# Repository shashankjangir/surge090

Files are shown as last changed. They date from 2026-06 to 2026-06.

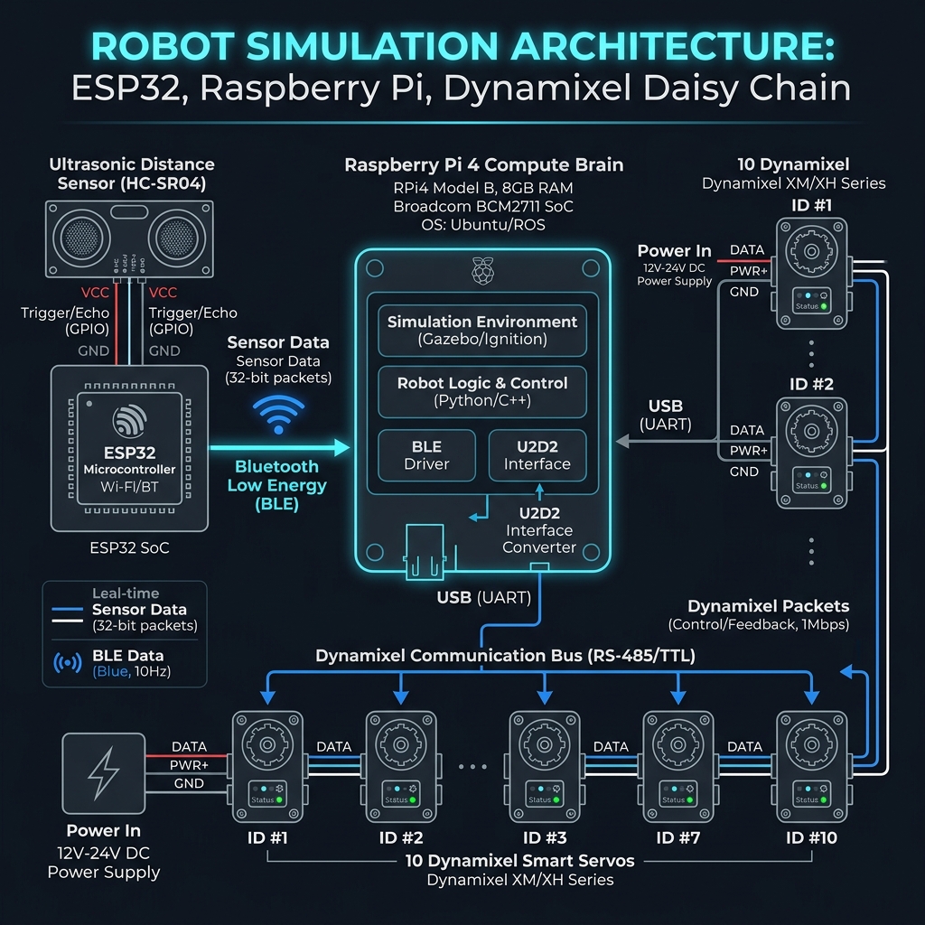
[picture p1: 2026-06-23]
Images/Simulation_Architecture.png

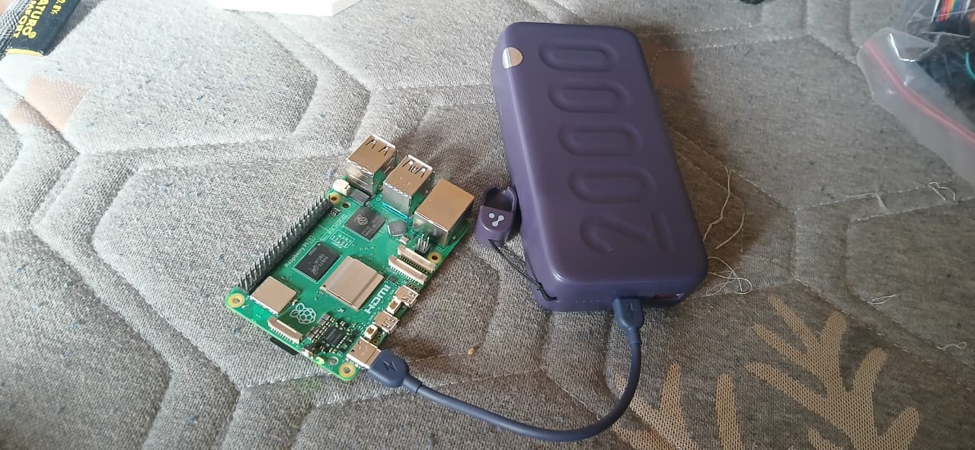
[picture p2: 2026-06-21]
Images/testing/running raspberry pi.jpeg

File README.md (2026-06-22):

        # SURGE-090 · Smart Snake Robot

        **SURGE Summer Research Programme · Indian Institute of Technology Delhi**

        ---

        ## Abstract

        SURGE-090 is a ten-degree-of-freedom, bio-inspired snake robot designed for locomotion in unstructured and confined environments. The platform employs sinusoidal lateral undulation to propel itself forward and uses proprioceptive motor-current sensing as a tactile collision detector — eliminating the need for any external proximity or force sensors. The control architecture is implemented entirely in Python running on a Raspberry Pi, communicating with ROBOTIS Dynamixel XL330 smart servo actuators over a TTL serial daisy chain.

        The project was developed as part of the **SURGE (Summer Undergraduate Research Grant for Excellence)** programme at **IIT Delhi**.

        ---

        ## Table of Contents

        1. [Features](#features)
        2. [System Architecture](#system-architecture)
        3. [Repository Structure](#repository-structure)
        4. [Hardware Requirements](#hardware-requirements)
        5. [Software Setup](#software-setup)
        6. [Running the Robot](#running-the-robot)
        7. [Module Reference](#module-reference)
        8. [CAD Files](#cad-files)
        9. [Documentation](#documentation)
        10. [Team](#team)

        ---

        ## Features

        | Feature | Description |
        |---|---|
        | **10-DOF Serpentine Gait** | Sinusoidal lateral undulation via a travelling sine wave propagated across all joints |
        | **Sensorless Obstacle Detection** | Motor current monitored at 50 Hz; stall current spike (> 350 mA) triggers evasion |
        | **Autonomous Evasion** | State machine: reverse (2.5 s) → side-aware turn (4 s) → resume forward |
        | **Side-Aware Turning** | Sign of the stalling motor's current determines which way the robot evades |
        | **Tethered & Untethered Modes** | Works via USB from a laptop or fully autonomous on on-board Raspberry Pi |
        | **3D-Printed Body** | All structural segments designed in SolidWorks; STEP and STL files provided |

        ---

        ## System Architecture

        ```
        ┌────────────────────────────────────────────┐
        │              Raspberry Pi 5                │
        │                                            │
        │  main.py  ──── Control Loop @ 50 Hz        │
        │     │                                      │
        │     ├──► src/obstacle_avoidance.py         │
        │     │        Current-based state machine   │
        │     │        SLITHER → REV → TURN → ...    │
        │     │                                      │
        │     ├──► src/snake_locomotion.py           │
        │     │        Sinusoidal gait generator     │
        │     │        turn_direction from avoidance │
        │     │                                      │
        │     └──► Dynamixel SDK                     │
        │               write4ByteTxRx (positions)   │
        │               read2ByteTxRx  (current)     │
        └──────────────┬─────────────────────────────┘
                │ USB  ←→  ROBOTIS U2D2
                ┌──────┴──────┐
                │  U2D2 + PHB  │  (power injection at 5V)
                └──────┬───────┘
                │ X3P TTL cables — daisy chain
        ┌───────────▼──────────────────────────────┐
        │  Motor 1 → Motor 2 → … → Motor 10        │
        │       ROBOTIS Dynamixel XL330-M288-T      │
        └───────────────────────────────────────────┘
        ```

        **Obstacle Evasion State Machine**

        ```
        SLITHER ──(|I| > 350 mA)──► SLITHER_REV (2.5 s)
                                        │
                                (timer expires)
                                        ▼
                                SLITHER_TURN (4.0 s)
                                        │
                                (timer expires)
                                        ▼
                                SLITHER
        ```

        ---

        ## Repository Structure

        ```
        surge090/
        ├── main.py                          # Entry point — 50 Hz control loop
        ├── servo_test.py                    # ⚠ DEPRECATED — SG90 GPIO prototype only
        ├── requirements.txt                 # Python dependencies
        ├── install_requirements.cmd         # Windows one-click installer
        ├── reorganise.ps1                   # Repo restructuring utility (run once)
        │
        ├── src/                             # Core robot software
        │   ├── __init__.py
        │   ├── robot_config.py              # All hardware constants & tuning parameters
        │   ├── utils.py                     # Shared utilities (current sign conversion)
        │   ├── snake_locomotion.py          # Sinusoidal gait engine
        │   ├── obstacle_avoidance.py        # Collision state machine
        │   ├── kinematics.py                # Bellows-model joint angle calculator
        │   ├── servo_driver.py              # HAL — mock + Dynamixel SDK interface
        │   └── torque_controller.py         # PD torque controller with compliance
        │
        ├── tests/                           # Hardware validation scripts
        │   ├── test_dynamixel_ping.py       # Ping all motors; report missing IDs
        │   └── test_motor_feedback.py       # Live position / velocity / current readout
        │
        ├── docs/                            # All project documentation
        │   ├── reports/
        │   │   ├── hardware_bom.md          # Bill of Materials (budget: ₹1,00,000)
        │   │   ├── starter_kit_manual.md    # First-time single-motor setup guide
        │   │   └── README_v1.md             # Archived v1 README
        │   ├── datasheets/
        │   │   ├── XL,XC-330.pdf            # ROBOTIS XL330 / XC330 datasheet
        │   │   ├── DYNAMIXEL_XL330_1__52682.png
        │   │   └── Raspberry-Pi-5-Pinout-.jpg
        │   ├── presentations/
        │   │   └── Smart_Snake_Robot_SURGE090_Progress_Review - Repaired.pptx
        │   ├── Component_flow.png           # System component flow diagram
        │   ├── SSH_LOGIN_INSTRUCTIONS.md
        │   ├── wiring_diagram.md
        │   ├── raspberry_pi_setup_guide.md
        │   ├── parts_and_safety.md
        │   └── additional_parts_spreadsheet.md
        │
        ├── cad/                             # SolidWorks / STEP / STL design files
        │   ├── segments/
        │   │   ├── segment1.SLDPRT / .STEP / _v1.STL
        │   │   └── segement2.SLDPRT / .STEP / _v1.STL
        │   ├── assembly/
        │   │   └── assembly.SLDASM
        │   └── motor_models/
        │       ├── XL,XC-330.stp           # Dynamixel motor reference model
        │       └── XL,XC-330.SLDASM
        │
        └── images/
        ├── hardware/                    # Motor & electronics product photos
        ├── cad/                         # CAD render screenshots
        └── testing/                     # Hardware test photos & demo video
        ```

        ---

        ## Hardware Requirements

        | Component | Qty | Approx. Cost (INR) | Notes |
        |---|:---:|---:|---|
        | Dynamixel XL330-M288-T | 10 + 2 spares | ₹36,000 | Core joints; 0.52 Nm @ 5V |
        | ROBOTIS U2D2 (USB-TTL) | 1 | ₹4,500 | Serial bridge to motors |
        | U2D2 Power Hub Board (PHB) | 1 | ₹1,500 | 5V power injection into bus |
        | Raspberry Pi 4 / 5 (4 GB) | 1 | ₹5,500 | On-board compute (optional for tethered) |
        | 5V / 10–20A SMPS *(tethered)* | 1 | ₹2,000 | Mean Well LRS-100-5 recommended |
        | *or* 2S LiPo + 5V UBEC *(untethered)* | 1 | ₹3,500 | Portable power option |
        | Dynamixel X3P Cables (×10) | 1 pack | ₹1,500 | Daisy-chain data + power |
        | F623ZZ Flange Bearings | 10 | ₹1,000 | Load relief for servo horns |
        | Braided Expandable Sleeving | 1 m | ₹2,000 | Robot "skin" — provides traction |
        | M2 / M2.5 Machine Screws | 1 kit | ₹500 | Mount 3D-printed brackets to motors |
        | **Total** | | **≈ ₹52,500** | Out of ₹1,00,000 budget |

        > Full specifications: [`docs/reports/hardware_bom.md`](docs/reports/hardware_bom.md)

        ---

        ## Software Setup

        ### Prerequisites

        - Python 3.8+
        - ROBOTIS U2D2 connected via USB

        ### 1. Clone

        ```bash
        git clone https://github.com/<org>/surge090.git
        cd surge090
        ```

        ### 2. Install Dependencies

        **Windows (one-click):**
        ```cmd
        install_requirements.cmd
        ```

        **Any platform:**
        ```bash
        pip install -r requirements.txt
        ```

        > Dependencies: `dynamixel-sdk >= 4.0.5`, `pyserial >= 3.5`

        ### 3. Set COM Port

        Open [`main.py`](main.py) and confirm the serial port for your system:

        ```python
        # Windows
        DEVICENAME = 'COM3'

        # Linux / Raspberry Pi
        DEVICENAME = '/dev/ttyUSB0'
        ```

        Find the correct port in **Device Manager** (Windows) or `ls /dev/ttyUSB*` (Linux).

        ### 4. Assign Motor IDs

        All motors ship with ID `1`. Assign unique IDs 1–10 one motor at a time:

        1. Plug in **one motor** to the U2D2 PHB.
        2. Open **Dynamixel Wizard 2.0** → Scan → change ID (1 through 10).
        3. Unplug; repeat for next motor.

        > Only after all 10 motors have unique IDs should you daisy-chain them together.

        ### 5. SSH to Raspberry Pi (if running untethered)

        ```powershell
        ssh smartsnake@snakerobo.local
        ```

        Full guide: [`docs/SSH_LOGIN_INSTRUCTIONS.md`](docs/SSH_LOGIN_INSTRUCTIONS.md)

        ---

        ## Running the Robot

        ### Verify All Motors

        ```bash
        python tests/test_dynamixel_ping.py
        ```

        Reports each motor ID found on the bus and explicitly lists any that are missing.

        ### Calibrate Obstacle Threshold

        ```bash
        python tests/test_motor_feedback.py
        ```

        Streams live Position / Velocity / Current (mA). Gently resist the horn to see the current spike that triggers obstacle detection.

        ### Start the Snake

        ```bash
        python main.py
        ```

        The snake initialises all motors, then begins the sinusoidal slither gait. Press **Ctrl + C** to halt — all motor torques are disabled cleanly in the `finally` block.

        ---

        ## Module Reference

        | Module | Class | Description |
        |---|---|---|
        | [`src/robot_config.py`](src/robot_config.py) | `Config`, `DynamixelAddr` | All hardware constants, tuning parameters, control table addresses |
        | [`src/utils.py`](src/utils.py) | — | `to_signed_current()` — XL330 two's complement current conversion |
        | [`src/snake_locomotion.py`](src/snake_locomotion.py) | `SnakeKinematics` | Sinusoidal gait: computes goal encoder positions for all joints |
        | [`src/obstacle_avoidance.py`](src/obstacle_avoidance.py) | `ObstacleAvoidance` | Current-based state machine; side-aware evasion turn direction |
        | [`src/kinematics.py`](src/kinematics.py) | `Kinematics` | Bellows-model curvature wave → joint angles (radians) |
        | [`src/servo_driver.py`](src/servo_driver.py) | `ServoDriver` | Hardware abstraction layer; mock simulation backend |
        | [`src/torque_controller.py`](src/torque_controller.py) | `TorqueController` | PD torque control with shape & radius modification modules |

        ### Gait Parameters (`src/robot_config.py`)

        | Parameter | Value | Description |
        |---|---|---|
        | `NUM_JOINTS` | 10 | Number of motors in daisy chain |
        | `ENCODER_CENTER` | 2048 | Neutral position (0° for XL330, range 0–4095) |
        | `OBSTACLE_CURRENT_THRESHOLD_MA` | 350 mA | Stall detection threshold |
        | `EVASION_REVERSE_DURATION_S` | 2.5 s | Time to reverse before turning |
        | `EVASION_TURN_DURATION_S` | 4.0 s | Time in turning gait before resuming |
        | `MAX_TORQUE_NM` | 0.52 Nm | XL330 stall torque (per ROBOTIS datasheet @ 5V) |

        ---

        ## CAD Files

        Designed in **SolidWorks**; exported to STEP and STL for cross-platform use.

        | File | Location | Description |
        |---|---|---|
        | `segment1.SLDPRT / .STEP / _v1.STL` | `cad/segments/` | Primary body segment |
        | `segement2.SLDPRT / .STEP / _v1.STL` | `cad/segments/` | Secondary body segment |
        | `assembly.SLDASM` | `cad/assembly/` | Full 10-motor robot assembly |
        | `XL,XC-330.stp` | `cad/motor_models/` | Dynamixel motor reference model |

        > Print settings: PLA or PETG recommended; 20% infill; 0.2 mm layer height.

        ---

        ## Documentation

        | Document | Path | Description |
        |---|---|---|
        | Hardware BOM | [`docs/reports/hardware_bom.md`](docs/reports/hardware_bom.md) | Full parts list with pricing |
        | Starter Kit Manual | [`docs/reports/starter_kit_manual.md`](docs/reports/starter_kit_manual.md) | Single-motor first-time setup |
        | Wiring Diagram | [`docs/wiring_diagram.md`](docs/wiring_diagram.md) | Power + data flow (Mermaid + text) |
        | Raspberry Pi Setup | [`docs/raspberry_pi_setup_guide.md`](docs/raspberry_pi_setup_guide.md) | OS configuration guide |
        | SSH Login | [`docs/SSH_LOGIN_INSTRUCTIONS.md`](docs/SSH_LOGIN_INSTRUCTIONS.md) | Connecting to the Pi from Windows |
        | Parts & Safety | [`docs/parts_and_safety.md`](docs/parts_and_safety.md) | Handling & safety guidelines |
        | Additional Parts | [`docs/additional_parts_spreadsheet.md`](docs/additional_parts_spreadsheet.md) | Supplementary components |
        | Progress Presentation | [`docs/presentations/`](docs/presentations/) | SURGE review slides |
        | Datasheets | [`docs/datasheets/`](docs/datasheets/) | XL330 datasheet, Pi pinout |

        ---

        ## Team

        **SURGE-090 — Smart Snake Robot**
        Indian Institute of Technology Delhi — Summer 2026

        | Member | Role |
        |---|---|
        | Shashank Jangir | Project Lead / Software |
        | Bhavesh | Hardware & Mechanical |
        | Mahima | Electronics & Wiring |

        ---

        ## Acknowledgements

        This project was carried out under the **SURGE (Summer Undergraduate Research Grant for Excellence)** programme at **IIT Delhi**. We thank our project supervisor and the Department of Mechanical Engineering for their guidance and laboratory resources.

        ---

        ## License

        © 2026 SURGE-090 Team, IIT Delhi. All rights reserved.
        This repository is shared for academic and research purposes only.

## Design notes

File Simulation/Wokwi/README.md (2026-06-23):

# SURGE-SNAKE ESP32 Sensor Node Wokwi Simulation

This directory contains the Wokwi simulation configuration and source code for the head-mounted distance sensor node.

## Hardware Configuration (`diagram.json`)

The simulation runs on an **ESP32 DevKit v4** connected to a **HC-SR04 Ultrasonic Distance Sensor**:
*   **VCC** -> ESP32 5V
*   **GND** -> ESP32 GND
*   **TRIG** -> ESP32 GPIO 5 (Output)
*   **ECHO** -> ESP32 GPIO 18 (Input)

## Firmware (`sketch.ino`)

The firmware:
1.  Triggers the HC-SR04 sensor at **10 Hz**.
2.  Reads the pulse-width echo response.
3.  Calculates the distance to any head-on obstacles in centimeters.
4.  Initializes the ESP32's Bluetooth stack and broadcasts as a Classic Bluetooth Serial device named `SURGE-SNAKE-ESP32`.
5.  Continuously transmits the data packet format `"DIST:<distance_cm>\r\n"` over Bluetooth Serial.

## How to Run the Wokwi Simulation

1.  Open [Wokwi.com](https://wokwi.com).
2.  Start a new ESP32 project.
3.  Replace the default `diagram.json`, `sketch.ino`, and `libraries.txt` with the files in this directory.
4.  Click the **Start Simulation** button in Wokwi.
5.  Observe the distance output printed in the virtual Serial Terminal. Drag the slider on the simulated HC-SR04 component to change the distance and see the outputs update dynamically.

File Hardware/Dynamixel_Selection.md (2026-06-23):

# SURGE-SNAKE Actuator Selection: ROBOTIS Dynamixel XL330

This document outlines the engineering rationale behind standardizing on the **ROBOTIS Dynamixel XL330-M288-T** smart servo motors for the SURGE-090 snake robot project.

---

## 1. Actuator Comparison

A comparison of candidate actuators was conducted to assess suitability for a 10-degree-of-freedom (10-DOF) bio-inspired snake robot:

| Parameter | TowerPro SG90 (Micro Servo) | Dynamixel AX-12A (Classic) | Dynamixel XL330-M288-T (Selected) |
| :--- | :--- | :--- | :--- |
| **Control Interface** | PWM (Open loop) | TTL Half-Duplex (1 Mbps) | **TTL Half-Duplex (115200 bps - 1 Mbps)** |
| **Feedback Sensors** | None | Position, Temperature, Load | **Contactless Absolute Encoder, Temp, Load, Current** |
| **Operating Voltage**| 4.8V - 6.0V | 9.0V - 12.0V | **3.7V - 6.0V (Standard 5.0V)** |
| **Stall Torque** | 0.18 Nm @ 5V | 1.50 Nm @ 12V | **0.52 Nm @ 5V** |
| **Weight** | 9 grams | 54 grams | **18 grams** |
| **Resolution** | N/A | 0.29° (10-bit potentiometer) | **0.088° (12-bit magnetic absolute encoder)** |
| **Daisy Chainable** | No (requires individual PWM lines) | Yes | **Yes** |

---

## 2. Selection Rationale

### A. Real-Time Proprioceptive Current Feedback (Critical)
The defining feature of the SURGE-090 control system is **sensorless tactile collision detection**. Traditional micro servos (like SG90) do not report operational current or load. The Dynamixel XL330 features an internal current sensor that is readable over the register map (`Present_Current` address `126`). 
By monitoring the motor current at 50 Hz, we can detect torque spikes (> 350 mA) corresponding to external obstacle resistance. This allows the robot to sense collisions across any part of its body without a single external tactile or force sensor.

### B. Weight and Scale Optimization
For snake robots, torque-to-weight ratio is crucial. 
*   **AX-12A** motors are too heavy (54g each, totaling 540g for 10 joints). This would require significantly larger structural linkages and higher torques just to lift the snake's own body.
*   **XL330** weighs only 18g (180g total for 10 joints), keeping the mechanical structure incredibly light and highly agile.

### C. Standard 5.0V Voltage Rail
Unlike the larger AX-12A or XM430 motors which require 12.0V, the XL330 is optimized for **5.0V operation**. 
*   Allows the use of a simple 5V SMPS or a standard 2S LiPo battery with a buck converter.
*   Significantly lowers the voltage hazards and weight of the battery pack.

### D. Single-Bus Daisy Chaining
Instead of running 10 separate PWM wires down the length of the snake (which would result in cable tangling, high friction, and restricted bending), the TTL bus allows a single 3-pin cable (X3P) to daisy-chain all 10 joints sequentially. The entire robot interfaces with the host computer (Raspberry Pi 4) via a single USB-to-TTL bridge (Robotis U2D2).

---

## 3. XL330-M288-T Technical Details

*   **Gear Ratio:** 288.4 : 1
*   **No-load Speed:** 39 rpm (at 5.0V)
*   **Stall Current:** 1.5 A
*   **Control Modes:** Current Control, Velocity Control, Position Control (0° - 360°), Extended Position Control (Multi-turn), Current-based Position Control, PWM Control.
*   **Communication Protocol:** Dynamixel Packet 2.0

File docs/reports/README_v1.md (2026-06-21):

# 🐍 SURGE-090: Self-Adaptive Smart Snake Robot

A bio-inspired, autonomous snake robot built on **Raspberry Pi** and **ROBOTIS Dynamixel XL330** servo motors. SURGE-090 uses a sinusoidal lateral undulation gait to slither forward and detects obstacles using only motor current feedback — no external sensors required.

---

## 📽️ Demo

> Hardware test footage is available in the project working folder.

---

## ✨ Key Features

- **10-DOF Serpentine Locomotion** — Sinusoidal lateral undulation gait implemented in pure Python
- **Sensorless Obstacle Detection** — Monitors motor current draw; a current spike (> 350 mA) signals a collision
- **Autonomous Evasion State Machine** — Automatically reverses for 2.5 s → turns for 4 s → resumes forward slither
- **Dual Operation Modes** — Tethered (via laptop USB) or fully untethered (on-board Raspberry Pi)
- **3D-Printed Body Segments** — SolidWorks + STEP + STL files included for all structural parts

---

## 🏗️ System Architecture

```
┌───────────────────────────────────────┐
│           Raspberry Pi 5              │
│                                       │
│  main.py  (Control Loop @ 50 Hz)      │
│    │                                  │
│    ├─► obstacle_avoidance.py          │
│    │     State Machine:               │
│    │     SLITHER → SLITHER_REV        │
│    │              → SLITHER_TURN      │
│    │              → SLITHER           │
│    │                                  │
│    ├─► snake_locomotion.py            │
│    │     Sinusoidal gait generation   │
│    │                                  │
│    └─► servo_driver.py               │
│          Dynamixel SDK calls          │
└──────────────┬────────────────────────┘
               │ USB (Micro-USB)
        ┌──────▼──────┐
        │  ROBOTIS U2D2│ ← USB-to-TTL adapter
        │  + PHB Board │ ← 5V power injection
        └──────┬───────┘
               │ X3P TTL cables (daisy chain)
    ┌──────────▼──────────────────────────┐
    │  Motor 1 ─── Motor 2 ─── ... ─── Motor 10  │
    │     Dynamixel XL330-M288-T          │
    └─────────────────────────────────────┘
```

---

## 📁 Repository Structure

```
git/
├── main.py                     # Entry point: control loop
├── servo_test.py               # Standalone servo testing script
├── requirements.txt            # Python dependencies
├── install_requirements.cmd    # Windows one-click dependency installer
├── hardware_bom.md             # Bill of Materials with costs (budget: ₹1,00,000)
├── starter_kit_manual.md       # Getting started with a single motor
├── SSH_LOGIN_INSTRUCTIONS.md   # How to SSH into the Raspberry Pi
├── Component_flow.png          # System architecture diagram
│
├── src/                        # Core robot logic (Python modules)
│   ├── snake_locomotion.py     # Sinusoidal gait & position calculator
│   ├── kinematics.py           # Joint angle kinematics
│   ├── servo_driver.py         # Low-level Dynamixel SDK wrapper
│   ├── obstacle_avoidance.py   # Current-based collision state machine
│   ├── torque_controller.py    # Torque limits & safety management
│   └── robot_config.py         # Centralized hardware constants
│
├── tests/                      # Hardware validation scripts
│   ├── test_dynamixel_ping.py  # Ping all motors to verify connectivity
│   └── test_motor_feedback.py  # Live motor position, velocity & current readout
│
├── 3d_parts/                   # CAD files for 3D-printed body
│   ├── segment1.SLDPRT / .STEP / .STL
│   ├── segement2.SLDPRT / .STEP / .STL
│   ├── XL,XC-330.stp           # Dynamixel motor reference model
│   └── assembly.SLDASM         # Full robot assembly
│
└── instruction/                # Setup & reference documentation
    ├── raspberry_pi_setup_guide.md
    ├── wiring_diagram.md
    ├── parts_and_safety.md
    └── additional_parts_spreadsheet.md
```

---

## 🛒 Hardware Requirements

| Component | Qty | Approx. Cost |
|---|:---:|---|
| Dynamixel XL330-M288-T (+ 2 spares) | 12 | ₹36,000 |
| ROBOTIS U2D2 (USB-to-TTL adapter) | 1 | ₹4,500 |
| U2D2 Power Hub Board (PHB) | 1 | ₹1,500 |
| Raspberry Pi 4/5 (4 GB) | 1 | ₹5,500 |
| 5V / 10–20A Power Supply *(tethered)* | 1 | ₹2,000 |
| *or* 2S LiPo + 5V UBEC *(untethered)* | 1 | ₹3,500 |
| Dynamixel X3P Cables (pack of 10) | 1 | ₹1,500 |
| F623ZZ Flange Bearings | 10 | ₹1,000 |
| Braided Expandable Sleeving ("skin") | 1 m | ₹2,000 |
| M2 / M2.5 Machine Screw Assortment | 1 | ₹500 |
| **Total** | | **~₹52,500 / ₹1,00,000** |

> See [`hardware_bom.md`](hardware_bom.md) for full specifications and sourcing notes.

---

## ⚙️ Software Setup

### Prerequisites

- Python 3.8+
- A Dynamixel-compatible serial port (USB via U2D2)

### 1. Clone the Repository

```bash
git clone <repo-url>
cd surge090
```

### 2. Install Dependencies

**Windows (one-click):**
```cmd
install_requirements.cmd
```

**Any platform:**
```bash
pip install -r requirements.txt
```

Dependencies: `dynamixel-sdk >= 4.0.5`, `pyserial >= 3.5`

### 3. Set Your COM Port

Open [`main.py`](main.py) and verify the serial port matches your system:

```python
# Windows
DEVICENAME = 'COM3'

# Linux / Raspberry Pi
DEVICENAME = '/dev/ttyUSB0'
```

Check the correct port in **Device Manager** (Windows) or with `ls /dev/ttyUSB*` (Linux).

### 4. Assign Motor IDs

All factory Dynamixel motors ship with ID `1`. You must assign unique IDs 1–10 **one at a time** before daisy-chaining:

1. Plug in **one motor** at a time to the U2D2 PHB.
2. Open **Dynamixel Wizard 2.0** on your PC.
3. Scan and change the motor's ID (1 through 10).
4. Unplug, plug in the next motor, repeat.

---

## 🚀 Running the Robot

### Quick Hardware Test (single motor)

```bash
python tests/test_motor_feedback.py
```

This enables torque, holds center position, and streams live **Position / Velocity / Current (mA)** to the terminal. Try forcing the horn with your fingers to see the current spike that drives obstacle detection.

### Ping All Motors

```bash
python tests/test_dynamixel_ping.py
```

Verifies that all 10 motors respond on the TTL bus.

### Single Servo Test

```bash
python servo_test.py
```

### Full Robot — Main Control Loop

```bash
python main.py
```

The snake will initialize all motors, then begin the sinusoidal slither gait. Press **Ctrl + C** to halt and safely disable all motor torques.

---

## 🧠 How It Works

### Locomotion — Lateral Undulation

Each odd-numbered motor is a **yaw** joint (lateral bending); each even-numbered motor is a **pitch** joint (held flat). The gait is produced by a travelling sine wave propagated along the motor chain:

```
position[i] = center + A · sin(ω·t − i·φ)
```

| Parameter | Value | Description |
|---|---|---|
| `amplitude` | 400 ticks | Peak deflection from centre |
| `frequency` | 3.0 | Wave propagation speed |
| `phase_shift` | 1.2 rad | Phase offset between adjacent segments |
| `center_pos` | 2048 | Neutral encoder count (0° for XL330) |

### Obstacle Avoidance — State Machine

The robot uses **motor current as a tactile sensor**. No external hardware is needed.

```
SLITHER ──(current > 350 mA)──► SLITHER_REV (2.5 s)
                                      │
                              (timer expires)
                                      ▼
                              SLITHER_TURN (4.0 s)
                                      │
                              (timer expires)
                                      ▼
                                  SLITHER
```

---

## 🖥️ Connecting to the Raspberry Pi (SSH)

```powershell
ssh smartsnake@snakerobo.local
```

Password: `xyz@1234`

> Ensure the Pi and your PC are on the same network (Wi-Fi or Ethernet). See [`SSH_LOGIN_INSTRUCTIONS.md`](SSH_LOGIN_INSTRUCTIONS.md) for full details.

---

## 🔌 Wiring Overview

```
Wall Outlet
  └─► 5V/10A Power Supply
        └─► U2D2 PHB (+ and - terminals)
              │
              ├─► U2D2 USB Interface ◄─► Raspberry Pi (USB-A)
              │
              └─► Motor 1 ◄─X3P─► Motor 2 ◄─X3P─► ... ◄─X3P─► Motor 10
```

For the full Mermaid flowchart and step-by-step wiring instructions, see [`instruction/wiring_diagram.md`](instruction/wiring_diagram.md).

---

## 📚 Documentation Index

| Document | Description |
|---|---|
| [`hardware_bom.md`](hardware_bom.md) | Full Bill of Materials with pricing |
| [`starter_kit_manual.md`](starter_kit_manual.md) | First-time setup guide (single motor) |
| [`SSH_LOGIN_INSTRUCTIONS.md`](SSH_LOGIN_INSTRUCTIONS.md) | SSH into the Raspberry Pi |
| [`instruction/raspberry_pi_setup_guide.md`](instruction/raspberry_pi_setup_guide.md) | Configure the Raspberry Pi OS |
| [`instruction/wiring_diagram.md`](instruction/wiring_diagram.md) | Full wiring flowchart & instructions |
| [`instruction/parts_and_safety.md`](instruction/parts_and_safety.md) | Safety guidelines |
| [`instruction/additional_parts_spreadsheet.md`](instruction/additional_parts_spreadsheet.md) | Supplementary parts list |

---

## 🔮 Future Roadmap

- [ ] Head-mounted distance sensor (HC-SR04 / VL53L0X) via ESP32 over Bluetooth
- [ ] 3D terrain navigation (pitch joint activation for vertical obstacles)
- [ ] ROS 2 integration for telemetry and remote control
- [ ] Wireless live dashboard (motor states, current draw, gait mode)

---

## 📄 License

This project is developed as part of the **SURGE-090** research initiative. All rights reserved by the project team.

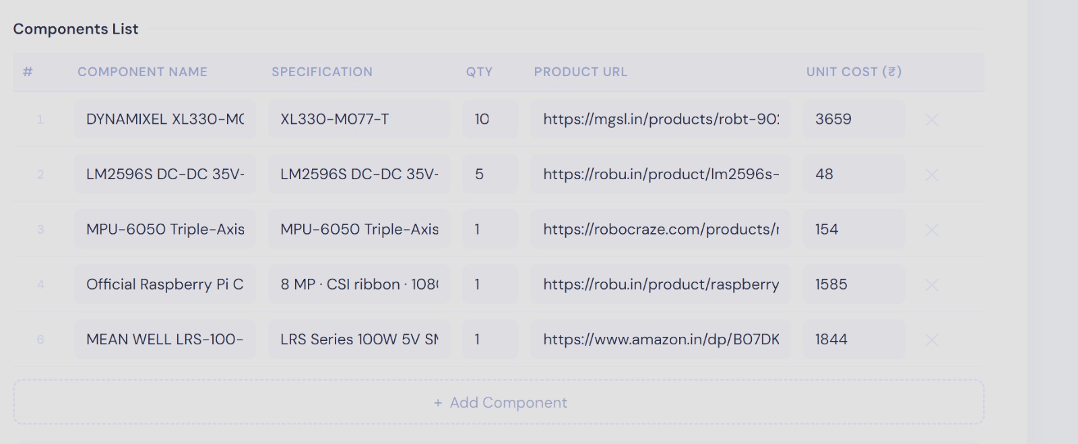
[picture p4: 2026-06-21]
Images/hardware/list 2.jpeg

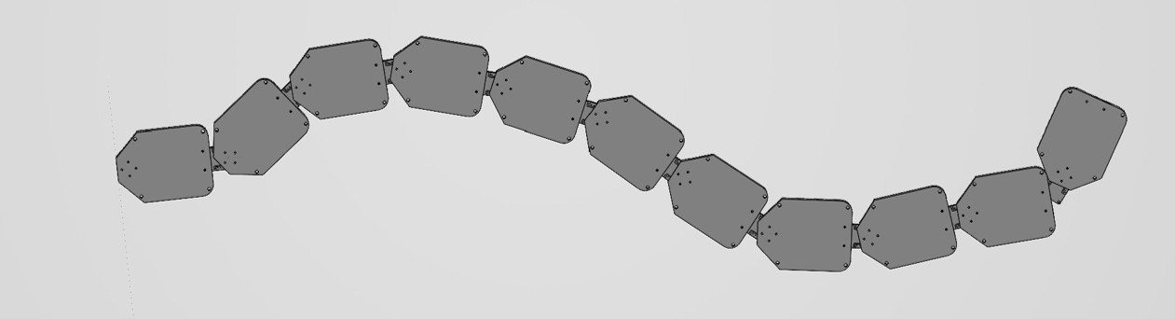
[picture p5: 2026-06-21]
Images/hardware/Picture1.jpg

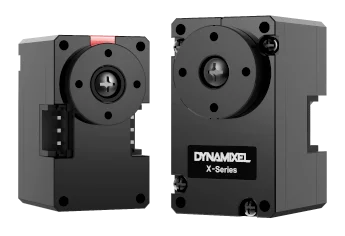
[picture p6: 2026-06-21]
Images/hardware/dynamixel.webp

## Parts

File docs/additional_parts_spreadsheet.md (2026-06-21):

# SURGE-SNAKE Additional Parts Spreadsheet

This document outlines everything else you need to complete the SURGE-SNAKE robot, explicitly **excluding the motors**. The items are separated into expensive structural/power upgrades and standard electronic components.

## 🔴 Expensive / Major Components
*These components represent the bulk of the remaining non-motor budget, primarily focusing on the mechanical structure and untethering the robot from the wall.*

| Component Name | Detailed Specifications | QTY | Est. Price (₹) | Trusted Product Link |
| :--- | :--- | :---: | :---: | :--- |
| **Robot Cable-X3P 180mm** | 3-pin JST TTL cables for Dynamixel X-Series. (Usually sold in packs of 10). You need these to daisy chain the remaining 8 joints. | 1 Pack | 2,659 | [MG Super Labs](https://www.mgsuperlabs.co.in/estore/Robot-Cable-X3P-180mm-10pcs) |
| **3D Printer Filament (PLA+)** | 1kg Spool, 1.75mm. Required to 3D print the custom U-brackets that connect the motors in the alternating pitch/yaw format. | 1 | 1,400 | [Robocraze (eSUN PLA+)](https://robocraze.com/products/esun-pla-pro-filament) |

---

## 🟢 Standard Components & Sensors
*These are the cheaper, everyday electronic components required for sensing, wiring, and friction.*

| Component Name | Detailed Specifications | QTY | Est. Price (₹) | Trusted Product Link |
| :--- | :--- | :---: | :---: | :--- |
| **High-Discharge 2S LiPo Battery** | 7.4V, ~2200mAh, 30C+ discharge rate. (Only needed if you want the snake to be completely wireless). | 1 | 1,200 | [Robocraze (Orange LiPo)](https://robocraze.com/collections/lipo-battery) |
| **VL53L0X Laser ToF Sensor** | High-precision Time-of-Flight laser ranging sensor for the head of the snake. Better accuracy than Ultrasonic. | 1 | 450 | [Robocraze (VL53L0X)](https://robocraze.com/products/gy-53-vl53l0x-laser-tof-flight-time-range-sensor-module) |
| **HC-SR04 Ultrasonic Sensor** | *Alternative to VL53L0X.* Cheaper, bulkier acoustic distance sensor. | 1 | 85 | [Robocraze (HC-SR04)](https://robocraze.com/products/ultrasonic-sensor-hc-sr04) |
| **5V 10A DC-DC Buck Converter** | Step-down module. **CRITICAL** if you buy the 7.4V LiPo battery. It drops the 7.4V down to the safe 5.0V needed for the XL330 motors. | 1 | 600 | [ElectronicsComp / Robocraze](https://robocraze.com/collections/step-down-buck-converter) |
| **Logic Level Shifter** | 4-channel bi-directional (3.3V to 5V). Protects the ESP32's 3.3V pins if you use a 5V sensor. | 1 | 60 | [Robocraze (Level Shifter)](https://robocraze.com/products/4-channel-iic-i2c-logic-level-converter) |
| **Jumper Wires (M-F & F-F)** | 40-pin ribbon cables (Dupont). Needed to wire the front sensor to the ESP32. | 1 Set | 120 | [Robocraze (Jumper Wires)](https://robocraze.com/products/jumper-wires-male-to-female-40-pcs) |
| **18 AWG Silicone Wire** | 1 Meter Red, 1 Meter Black. Thick wire to connect the 5V 10A Power Supply to the U2D2 PHB Terminal Block safely. | 1 | 150 | [Robocraze (Silicone Wire)](https://robocraze.com) |
| **TPU Filament OR Rubber Pads** | **CRITICAL for Locomotion.** Anti-slip rubber adhesive pads (or 3D printed TPU feet) for the underside of the brackets to provide Friction Anisotropy. | 1 Pack | 200 | [Amazon India (Rubber Pads)](https://www.amazon.in) |

---

### Usage Notes:
1. **Friction Pads:** You can simply buy a sheet of adhesive 3M rubber anti-slip pads from Amazon or a local hardware store and cut them into strips for the belly of the snake. You do not need to 3D print these if you don't have TPU filament.
2. **LiPo Battery:** If you stick to using the tethered 5V 10A power supply you already ordered, you can completely ignore the LiPo Battery and the 5V Buck Converter.
3. **Cables:** Ensure the Dynamixel cables you buy are exactly **X3P** (JST connectors), as older Bioloid AX-12 cables will not fit the XL330.

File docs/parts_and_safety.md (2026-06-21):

# SURGE-SNAKE Parts and Safety Protocol

## Parts Ordered (Existing Inventory)
1. **SD card (32GB A1 class 10)** - For Raspberry Pi OS.
2. **Raspberry Pi 4 Model B (4GB RAM)** - Main compute brain.
3. **Power Adapter (USB-C 5V 3A)** - Dedicated power for the Raspberry Pi.
4. **Raspberry Pi Heat Sink (Double Fans)** - Cooling for Pi.
5. **Dynamixel XL330-M288-T (x2)** - Smart servos for the joints (currently 2 for testing).
6. **U2D2 USB Interface** - Translates USB to TTL half-duplex for the Dynamixels.
7. **U2D2 PHB Power Hub Board** - Distributes power and signals to the daisy-chained Dynamixels.
8. **Robot Cable X3P 180mm** - TTL cables to connect motors.
9. **Power Supply (5V 10A - 50W)** - Power source for the Dynamixel network.
10. **ESP32 (38 pin WiFi + Bluetooth)** - Sensor node/secondary controller.

## Missing Parts (To Be Ordered)
Based on the plan for a 10-motor serpentine robot:

1. **Additional Dynamixel XL330-M288-T (x8):** To complete the 10-motor setup (5 pitch, 5 yaw).
2. **Dynamixel X3P Cables (x8):** Need more cables to daisy-chain the new motors.
3. **Mechanical Brackets / Frame:**
   - 3D Printed custom links OR BIOLOID frame components to mechanically connect the motors in alternating Pitch/Yaw configurations.
4. **Friction Pads (CRITICAL):**
   - TPU feet, rubber pads, or passive wheels (that only roll forward/back) attached to the underside of the snake. *Required for Friction Anisotropy so the snake pushes forward instead of wriggling in place.*
5. **Front Obstacle Sensor:** 
   - 1x **HC-SR04** (Ultrasonic) or **VL53L0X** (Time-of-Flight) module to attach to the ESP32 for head-on obstacle detection.
5. **Miscellaneous Wiring:** 
   - Jumper wires to connect ESP32 and sensors.
   - 18 AWG wires to connect the 5V 10A Power Supply to the U2D2 PHB Terminal block.

---

## ⚡ Safety Protocols & Voltage Limits ⚡

> [!CAUTION]
> **CRITICAL: NEVER exceed 6.0V on the Dynamixel XL330 network!**

### 1. Motor Power Line (5V System)
- **Component Limit:** Dynamixel XL330-M288-T operates safely between **3.7V and 6.0V**.
- **Current Setup:** You are using a 5V 10A power supply. This is **PERFECT** and very safe. The U2D2 PHB simply passes the input voltage directly to the motors.
- **Safety Rule:** Ensure the polarity (+ and -) from the 5V power supply to the U2D2 PHB terminal block is correct. Reversing the polarity will permanently damage the U2D2 PHB and the motors.

### 2. Microcontroller Power Limits
- **Raspberry Pi 4:** Must be powered via its official 5V 3A USB-C adapter. Do not back-power it from the U2D2 PHB. Keep the logic connections (USB from Pi to U2D2) isolated from the motor power supply.
- **ESP32:** Can be powered via USB (5V) or via its VIN/VCC pin (5V). Its GPIO pins are **3.3V logic ONLY**. Do not connect a 5V sensor output directly to an ESP32 GPIO pin without a logic level shifter or a voltage divider.

### 3. Untethered / Battery Operation (Future Upgrade)
If you decide to make the snake wireless, you cannot plug a 2S LiPo battery (7.4V - 8.4V) directly into the U2D2 PHB, as it will fry the 6.0V limit XL330 motors.
- **Required Safety Barrier:** You will need a **5V Buck Converter (Step-Down Module)** rated for at least 10 Amps to sit between the LiPo battery and the U2D2 PHB.

### 4. Overcurrent & Stall Safety
The Python code includes software safety limits to prevent motors from burning out if the snake gets stuck on an obstacle:
- We read the `Present_Current` of each Dynamixel. 
- If the current exceeds a set threshold (e.g., indicating a stall or collision), the robot will automatically halt and execute an avoidance maneuver.

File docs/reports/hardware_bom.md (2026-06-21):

# Hardware Bill of Materials (Budget: ₹1,00,000)

This document contains the finalized hardware required to build the 10-motor **SURGE-SNAKE** using the Dynamixel ecosystem. 

With a budget of **1 Lakh (₹1,00,000)** and standardizing on the **Dynamixel XL330-M288** motors, the project comes in significantly under budget, leaving plenty of room for spares, future sensor upgrades, and high-quality mechanical components.

---

## 1. Core Actuators (Servos) - *Require 10 Units*

| Component | Specs & Torque | Approx. Cost (10 Units) | Role in Robot |
| :--- | :--- | :--- | :--- |
| **Dynamixel XL330-M288-T** | 0.5 Nm, 5V, Contactless Absolute Encoder | ~₹30,000 (₹3k ea) | The core joints of the snake. Provides extremely precise position, velocity, and current (load) feedback crucial for obstacle avoidance. |
| **Spare Motors** | Same as above | ~₹6,000 (2 extra) | Highly recommended to buy 2 spares in case of gear stripping during extreme physical testing. |

---

## 2. Computing Brain & Interface

The Dynamixel motors require a dedicated USB interface to talk to your computer or Raspberry Pi.

| Component | Specs | Approx. Cost | Role in Robot |
| :--- | :--- | :--- | :--- |
| **Robotis U2D2** | USB to TTL Converter | ~₹4,500 | Plugs into your PC/Pi and outputs the 3-pin TTL data signal for the Dynamixel motors. |
| **Robotis U2D2 Power Hub Board (PHB)** | Power Injector | ~₹1,500 | Mounts to the U2D2. Combines the data signal with raw 5V power so the motors don't fry your USB port. |
| **Raspberry Pi 4 (Optional)** | 4GB RAM, Linux OS | ~₹5,500 | If you want the snake untethered from your laptop, the Pi will run the `main.py` Python code onboard. |

---

## 3. Power Supply

The **XL330-M288** motors require **5 Volts** (not 12V!). Powering 10 motors at stall torque requires roughly 10 Amps to 15 Amps of current.

| Component Option | Specs | Approx. Cost | Pros / Cons |
| :--- | :--- | :--- | :--- |
| **Mean Well LRS-100-5 (Tethered)** | 5V, 20A Industrial SMPS | ~₹2,000 | **Pros:** Extremely reliable, clean power for testing on a desk.<br>**Cons:** Keeps the snake tethered to the wall. |
| **2S LiPo Battery + 5V UBEC (Untethered)** | 7.4V LiPo + 10A 5V Step-Down | ~₹3,500 | **Pros:** Makes the snake fully wireless.<br>**Cons:** Requires careful voltage monitoring and a fire-safe charger. |

---

## 4. Wiring & Mechanical Setup

| Component | Specs | Approx. Cost |
| :--- | :--- | :--- |
| **Dynamixel X3P Cables** | 100mm to 150mm lengths (Pack of 10) | ~₹1,500 | Daisy-chains the data and power from one motor to the next. |
| **F623ZZ Flange Bearings** | For opposite side of servo horn | ~₹1,000 | Takes the mechanical load off the servo horn, preventing snapped shafts. |
| **Braided Expandable Sleeving** | Rubberized mesh tube | ~₹2,000 | Acts as the "skin" of the snake. Expands as it bends and provides traction against the floor. |
| **M2 & M2.5 Machine Screws** | Assorted Kit | ~₹500 | For mounting the 3D printed brackets to the Dynamixels. |

---

## Summary Recommendation 

**Total Estimated Cost: ~₹52,500 INR** (out of ₹1,00,000 budget)

Standardizing on the **Dynamixel XL330-M288** is highly efficient. It operates at 5V, saving weight on batteries, and integrates perfectly with the official Robotis `dynamixel_sdk`. The Python code provided in this repository is designed specifically for this exact hardware list.

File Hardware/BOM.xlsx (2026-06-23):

SURGE-SNAKE Hardware Bill of Materials
Total Budget: INR 1,00,000 | Standardized on Dynamixel XL330 Ecosystem
1. Core Actuators (Servos)
Component | Specs & Torque | Qty | Unit Price (INR) | Total Price (INR) | Role in Robot
Dynamixel XL330-M288-T | 0.52 Nm @ 5V, Contactless Absolute Encoder | 10 | ₹3000 | ₹30000 | Core joints of the snake robot. Provides precise position, velocity, and current feedback.
Spare Motors | Same as above | 2 | ₹3000 | ₹6000 | Recommended spares for testing and replacement.
Subtotal
2. Computing Brain & Interface
Component | Specs | Qty | Unit Price (INR) | Total Price (INR) | Role in Robot
Robotis U2D2 | USB to TTL Serial Converter | 1 | ₹4500 | ₹4500 | Plugs into computer/Pi to translate USB to TTL half-duplex signals.
Robotis U2D2 Power Hub Board (PHB) | Power Injector Board | 1 | ₹1500 | ₹1500 | Combines power and TTL signals for daisy-chained motors.
Raspberry Pi 4 | 4GB RAM, Linux OS, USB-C Power | 1 | ₹5500 | ₹5500 | On-board compute brain running python control loop.
Subtotal
3. Power Supply
Component | Specs | Qty | Unit Price (INR) | Total Price (INR) | Pros / Cons
Mean Well LRS-100-5 (Tethered) | 5V, 20A Industrial SMPS | 1 | ₹2000 | ₹2000 | Pros: extremely reliable, clean power for testing. Cons: tethered.
2S LiPo Battery + 5V UBEC (Untethered) | 7.4V LiPo + 10A 5V Step-Down Converter | 1 | ₹3500 | ₹3500 | Pros: makes robot wireless. Cons: requires voltage monitoring.
Subtotal
4. Wiring & Mechanical Setup
Component | Specs | Qty | Unit Price (INR) | Total Price (INR) | Notes
Dynamixel X3P Cables | 100mm to 150mm length (Pack of 10) | 1 | ₹1500 | ₹1500 | Daisy-chains power and data between adjacent joints.
F623ZZ Flange Bearings | Load relief bearings | 10 | ₹100 | ₹1000 | Relieves radial loads off the servo horn, preventing shaft failure.
Braided Expandable Sleeving | Rubberized mesh tube (1 meter) | 1 | ₹2000 | ₹2000 | Acts as the snake skin; provides friction anisotropy and protection.
M2 & M2.5 Machine Screws | Assorted Fastener Kit | 1 | ₹500 | ₹500 | For mounting custom 3D printed brackets to motor frames.
Subtotal
GRAND TOTAL

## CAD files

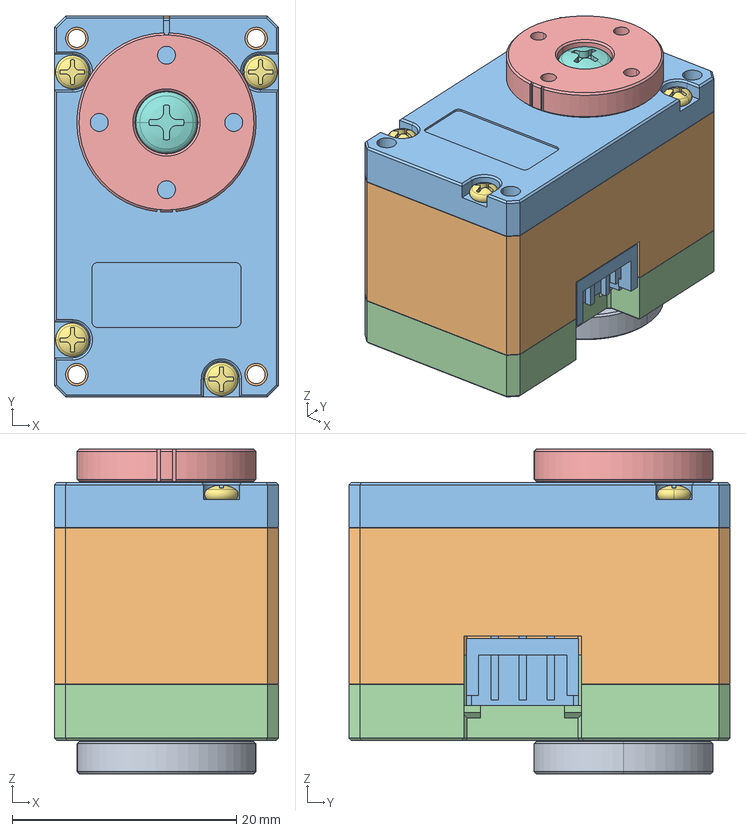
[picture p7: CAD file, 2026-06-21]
CAD/motor_models/XL,XC-330.stp
20.0 x 34.0 x 29.0 mm
DC15_A01_CASE_M_DUMMY
DC15_A01_CASE_F_DUMMY
DC15_A01_CASE_B_DUMMY
DC15_A01_HORN_DUMMY
DC15_A01_LED_CAP2_DUMMY
PHS_1_7X20_5_DC10 x 4
BTS2_M2_6X8 x 2
DC15_A01_HORN_IDLE2_DUMMY
DC15_A01_IDLE_CAP_DUMMY
B3B-EH x 2

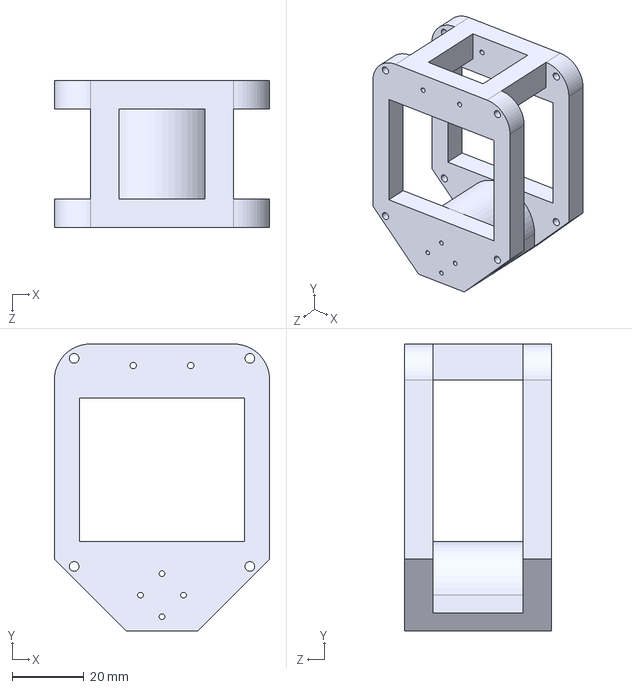
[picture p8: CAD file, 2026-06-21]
CAD/segments/segement2.STEP
60.0 x 80.0 x 41.0 mm

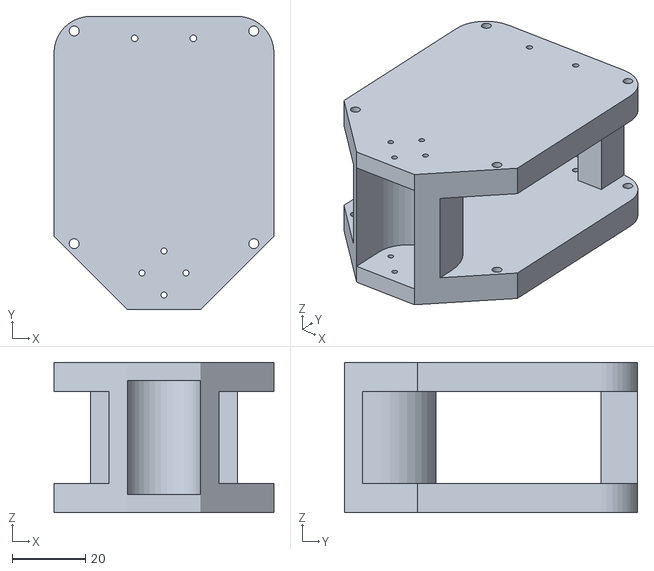
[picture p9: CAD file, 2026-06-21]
CAD/segments/segment1_v1.STL
60.0 x 80.0 x 41.0

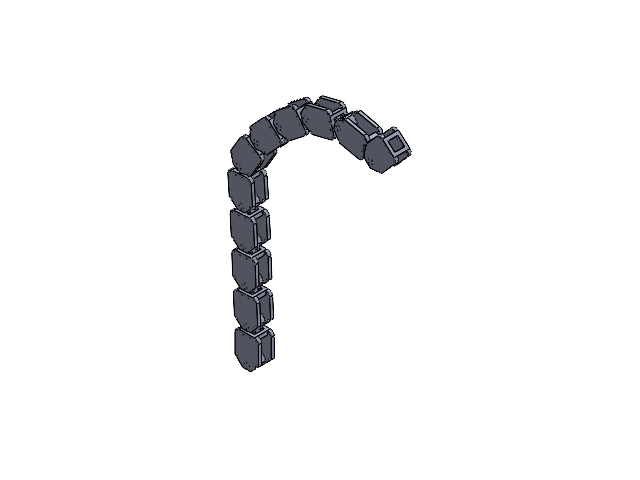
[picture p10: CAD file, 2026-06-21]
CAD/assembly/assembly.SLDASM
segment1 (2) x 11
DC15_A01_CASE_M_DUMMY.stp x 10
DC15_A01_CASE_F_DUMMY.stp x 10
DC15_A01_CASE_B_DUMMY.stp x 10
DC15_A01_HORN_DUMMY.stp x 10
DC15_A01_LED_CAP2_DUMMY.stp x 10
PHS_1_7X20_5_DC10.stp x 40
BTS2_M2_6X8.stp x 20
DC15_A01_HORN_IDLE2_DUMMY.stp x 10
DC15_A01_IDLE_CAP_DUMMY.stp x 10
B3B-EH.stp x 20

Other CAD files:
CAD/segments/segement2_v1.STL
CAD/segments/segment1.STEP
CAD/segments/segment1 (2).SLDPRT
CAD/motor_models/XL,XC-330.SLDASM
CAD/segments/segement2.SLDPRT
CAD/segments/segment1.SLDPRT

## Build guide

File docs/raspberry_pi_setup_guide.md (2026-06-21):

# SURGE-SNAKE: Raspberry Pi Setup & Execution Guide

This guide will walk you through flashing the OS, deploying this code to your Raspberry Pi, and running the physical robot.

## Phase 1: Burning the Raspberry Pi OS
Since the Pi will sit inside the snake, it will run "headless" (without a monitor).

1. **Download Raspberry Pi Imager:** Install it on your Windows PC from the official Raspberry Pi website.
2. **Insert SD Card:** Plug the 32GB SD card into your PC.
3. **Configure Imager:**
   - **Device:** Select `Raspberry Pi 4`.
   - **OS:** Choose `Raspberry Pi OS (64-bit)` (Lite is fine if you don't need a desktop UI, otherwise choose Full).
   - **Storage:** Select your 32GB SD Card.
4. **OS Customization (Crucial for Headless Setup):**
   - Click the gear icon (or "Edit Settings") before writing.
   - Check **Set hostname** (e.g., `surgesnake.local`).
   - Check **Enable SSH** (Use password authentication).
   - Set **Username and Password** (e.g., user: `pi`, pass: `password`).
   - Check **Configure wireless LAN** and enter your home Wi-Fi SSID and Password.
5. **Write:** Click "Write" to burn the OS.

---

## Phase 2: Hardware Wiring & Booting
1. Insert the flashed SD card into the Raspberry Pi.
2. Plug the USB-C 5V 3A adapter into the Pi to boot it up.
3. Plug the **U2D2 Interface** into one of the Pi's USB ports.
4. Connect the **5V 10A Power Supply** to the **U2D2 PHB Power Board** (Double check positive/negative polarity!).
5. Daisy-chain your 2 Dynamixel motors to the U2D2 PHB.

---

## Phase 3: Accessing the Pi and Installing Dependencies
Wait about 2 minutes for the Pi to boot and connect to your Wi-Fi.

1. Open PowerShell on your Windows PC and SSH into the Pi:
   ```bash
   ssh pi@surgesnake.local
   ```
   *(Accept the fingerprint prompt and enter your password).*
2. Once inside the Pi, update the system and install the required Python libraries:
   ```bash
   sudo apt update
   sudo apt upgrade -y
   sudo apt install python3-pip
   pip install dynamixel-sdk pyserial
   ```
3. Add your user to the `dialout` group so Python can access the USB port without root permissions:
   ```bash
   sudo usermod -aG dialout pi
   ```
   *You must log out and log back in (or reboot the Pi) for this to take effect.*

---

## Phase 4: Copying the Code (Windows to Pi)
You have this `SURGE-SNAKE` folder on your Windows Desktop. We need to send it to the Pi.

### Method A: Using SCP (Command Line)
Open a **new** PowerShell window on your Windows PC (not the SSH session) and run:
```bash
scp -r "C:\Users\bansi\OneDrive\Desktop\SURGE-SNAKE" pi@surgesnake.local:/home/pi/
```
This will copy the entire folder over the network.

### Method B: Using WinSCP (GUI)
1. Download and install [WinSCP](https://winscp.net/).
2. Connect to `surgesnake.local` using your Pi's username and password.
3. Drag and drop the `SURGE-SNAKE` folder from your desktop into the `/home/pi/` directory.

> **Note on USB Ports:** 
> I have already updated the Python scripts to automatically detect that they are running on a Raspberry Pi (Linux) and they will look for the U2D2 at `/dev/ttyUSB0` instead of `COM3`. You do not need to manually change the code!

---

## Phase 5: Testing & Running
SSH back into your Pi (`ssh pi@surgesnake.local`) and navigate to the folder:
```bash
cd SURGE-SNAKE
```

**1. Ping the Motors:**
```bash
python3 tests/test_dynamixel_ping.py
```
*You should see output confirming communication with Motor 1 and Motor 2.*

**2. Test Obstacle Load Detection:**
```bash
python3 tests/test_motor_feedback.py
```
*Squeeze the motor lightly while it spins; watch the current/mA reading spike.*

**3. Run the Main Snake Loop:**
```bash
python3 main.py
```
*The motors will begin executing the rolling helix wave. If you grab one, it will trigger the reverse-and-turn evasion sequence!*

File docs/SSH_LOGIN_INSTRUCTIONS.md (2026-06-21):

# Raspberry Pi SSH Login Instructions

These are the step-by-step instructions to log into the Raspberry Pi from your Windows computer.

## Prerequisites
- Ensure your Raspberry Pi is powered on.
- Ensure your Raspberry Pi is on the same network as your PC. This means EITHER:
  - You have an **Ethernet cable** directly connecting the Pi to your PC.
  - OR, both devices are connected to the same **Wi-Fi network / hotspot**.

## Login Steps

**Step 1: Open PowerShell**
1. Press the **Windows Key** on your keyboard.
2. Type `PowerShell` and press **Enter**.

**Step 2: Enter the SSH Command**
In the PowerShell window, type the following command and press **Enter**:
```powershell
ssh smartsnake@snakerobo.local
```

**Step 3: Security Prompt (First Time Only)**
If you see a message asking: `Are you sure you want to continue connecting (yes/no/[fingerprint])?`
Type `yes` and press **Enter**.

**Step 4: Enter Password**
When prompted for the password, type:
```text
xyz@1234
```
*Note: The password will **not** appear on the screen as you type it. This is a normal security feature. Just type the characters and press **Enter**.*

## Success!
Once you see the prompt change to `smartsnake@snakerobo:~ $`, you are successfully logged into the Raspberry Pi and can start running commands.

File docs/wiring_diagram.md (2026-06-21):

# SURGE-SNAKE Wiring & Circuit Diagram

This document contains the exact wiring instructions and a visual flowchart showing how power and data travel through your robot.

## 1. Visual Flowchart
*If your markdown viewer supports Mermaid, this will render as a visual flowchart. Otherwise, follow the text-based connections below.*

```mermaid
graph TD
    subgraph Power Source (Mains)
        Wall[Wall Outlet AC] -->|AC Input| PS[5V 10A Power Supply]
        PS -->|Red Wire / V+| PHB_V[U2D2 PHB Terminal: +]
        PS -->|Black Wire / V-| PHB_G[U2D2 PHB Terminal: -]
    end

    subgraph Computing Brain
        PiPS[Official USB-C Pi Adapter] -->|5V 3A Power| PI[Raspberry Pi 4]
        PI <-->|Data: USB A to Micro USB| U2D2[U2D2 USB Interface]
    end

    subgraph Motor Network (Daisy Chain)
        U2D2 -->|Plugs Directly On Top| PHB[U2D2 PHB Power Hub]
        PHB_V --> PHB
        PHB_G --> PHB
        
        PHB <-->|X3P Robot Cable| M1[Dynamixel XL330 Motor 1]
        M1 <-->|X3P Robot Cable| M2[Dynamixel XL330 Motor 2]
        M2 <-.->|X3P Robot Cable| M10[Dynamixel XL330 Motor 10]
    end
    
    subgraph Future Head Sensors
        PI -.->|Bluetooth / WiFi Data| ESP[ESP32 Microcontroller]
        ESP <-->|Jumper Wires| SEN[HC-SR04 / VL53L0X Sensor]
    end

    style PS fill:#f9d0c4,stroke:#333,stroke-width:2px
    style PI fill:#c4e3f9,stroke:#333,stroke-width:2px
    style PHB fill:#d4f9c4,stroke:#333,stroke-width:2px
    style M1 fill:#fff2cc,stroke:#333
    style M2 fill:#fff2cc,stroke:#333
    style M10 fill:#fff2cc,stroke:#333
```

---

## 2. Step-by-Step Exact Wiring Instructions

### Step 1: Powering the Pi
1. Plug the **Official Raspberry Pi USB-C Power Adapter** into the wall.
2. Plug the USB-C end into the **Raspberry Pi 4**.
   - *Safety Note: NEVER try to power the Pi from the U2D2 or the 10A power supply. Always keep its power isolated via the official adapter to prevent blowing the Pi's fuses.*

### Step 2: The Motor Power Supply
1. Take your **5V 10A Power Supply**. Wire its AC input terminals (L, N, G) to a standard wall plug cable.
2. Take two thick wires (18 AWG recommended). 
3. Connect one wire to the **V+** terminal on the power supply, and the other to the **V- (or COM)** terminal.
4. On the **U2D2 PHB Power Hub Board**, locate the 2-pin screw terminal block.
5. Screw the **V+** wire into the **+** slot on the PHB.
6. Screw the **V-** wire into the **-** slot on the PHB.

### Step 3: The Data Bridge
1. The **U2D2 USB Interface** is a small stick. It physically mounts onto the pins of the **U2D2 PHB Power Hub Board**. Press it down firmly so the pins mate.
2. Use a Micro-USB to USB-A cable. Plug the Micro end into the **U2D2 USB Interface**, and plug the USB-A end into any USB 3.0 (blue) port on the **Raspberry Pi 4**.
   - *This provides the data link between the Pi's Python script and the motors.*

### Step 4: The Daisy Chain (Motors)
1. The XL330 motors have two identical ports on the back.
2. Take a **Robot Cable X3P**. Plug one end into any 3-pin TTL port on the **U2D2 PHB Power Hub Board**.
3. Plug the other end into either port on **Motor 1**.
4. Take a second **Robot Cable X3P**. Plug it into the remaining port on **Motor 1**.
5. Plug the other end into **Motor 2**.
6. Repeat this process for all remaining motors. Because the ports are identical, it does not matter which of the two ports on the motor is "in" or "out".

### Step 5: Setting Motor IDs (Crucial!)
Out of the box, all Dynamixel motors have an ID of `1`. If you daisy-chain them immediately, the code will fail because it cannot distinguish between them.
1. Plug in **only ONE motor** to the U2D2 PHB.
2. Use the **Dynamixel Wizard 2.0** software on your Windows PC to change its ID to `1`.
3. Unplug it. Plug in the next motor. Change its ID to `2`.
4. Repeat until you have motors 1 through 10. *Only then* can you daisy chain them all together at once!

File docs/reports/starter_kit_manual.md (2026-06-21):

# Snake Robot Starter Kit Manual (Dynamixel Edition)

Welcome to the Starter Kit for the self-adaptive snake robot project! This manual focuses on testing individual motor movement, reading current (load) feedback, and testing the `dynamixel_sdk` using Python.

By the end of this guide, you will have your first Dynamixel XL330 motor spinning and reporting its load back to your computer.

---

## 1. Hardware Requirements for Testing

To begin testing, you need the following connected to your computer:
1. **Dynamixel XL330-M288 Motor** (At least 1 unit, though you can daisy chain 2 for this test)
2. **Robotis U2D2** (USB to TTL interface)
3. **U2D2 Power Hub Board (PHB)** (To inject power into the data line)
4. **5V Power Supply** (e.g., Mean Well SMPS or a 5V bench power supply capable of at least 3A)
5. **Dynamixel X3P Cables** (To connect everything together)

---

## 2. Hardware Assembly

1. Connect the **U2D2** to your computer via USB.
2. Mount the **U2D2 Power Hub Board** onto the U2D2.
3. Wire the **5V Power Supply** to the screw terminals on the Power Hub Board. Make sure the polarity (+ and -) is correct.
4. Plug one end of the **X3P Cable** into the Power Hub Board, and the other end into your **Dynamixel XL330** motor.
5. Turn on the 5V power supply. The LED on the back of the Dynamixel motor should flash red once to indicate it has power.

---

## 3. Software Setup (Python)

We are using Python to control the snake robot, relying on the official `dynamixel_sdk`.

### Step 3.1: Identify the COM Port
- **Windows:** Open Device Manager, look under "Ports (COM & LPT)" and find the "USB Serial Port". Note the number (e.g., `COM3`).
- **Linux/Raspberry Pi:** Open a terminal and run `ls /dev/ttyUSB*`. It will usually be `/dev/ttyUSB0`.

### Step 3.2: Install Requirements
Open a terminal in the root of the `SURGE-SNAKE` project and install the dependencies:
```bash
pip install -r requirements.txt
```
*(This installs `dynamixel-sdk` and other necessary libraries).*

---

## 4. Running the Feedback Test

To ensure everything is working and to calibrate your obstacle avoidance thresholds, run the motor feedback test script.

1. Open `tests/test_motor_feedback.py` in your code editor.
2. Verify the configuration at the top of the file:
   - Make sure `DXL_ID = 1` matches your motor's ID (brand new motors default to ID 1).
   - Ensure `DEVICENAME` is set to your COM port (e.g., `'COM3'`).
3. Run the script:
   ```bash
   python tests/test_motor_feedback.py
   ```

### What to Expect:
- The motor will enable its torque and stiffen up, holding its center position.
- Your terminal will print a continuous stream of Position, Velocity, and Current (mA).
- **The Obstacle Test:** Gently try to force the motor horn to rotate with your fingers. You will see the `Current (mA)` value spike up on your screen. This spike is exactly what the `ObstacleAvoidance` script in `main.py` looks for to detect collisions!

---

## 5. Next Steps

Once the feedback test is successful, you can connect all **10 motors** in a daisy chain. 
*(Note: You will need to use the Dynamixel Wizard 2.0 software to change each motor's ID from 1 to 10 so they don't conflict on the network).*

After setting the IDs, you are ready to run `python main.py` and watch the snake slither!

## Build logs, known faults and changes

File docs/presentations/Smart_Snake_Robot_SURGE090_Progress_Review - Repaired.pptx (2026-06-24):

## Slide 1

GROUP CODE · SURGE 090

INSTITUTION

Indian Institute of Technology, Delhi

Progress Review (Design & Development)

Smart Snake Robot

with Dynamixel Smart Servo Motors

PROJECT GUIDE

Professor Amartansh Dubey

Shashank Jangir

ENTRY NO.

2024EE11048

Bhavesh Bansiwal

ENTRY NO.

2024ME10487

Mahima Chotiya

ENTRY NO.

2024ME11187

PROJECT REPOSITORY

https://github.com/shashankjangir/surge090

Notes: Title slide for the 25% progress review of the Smart Snake Robot project, Group SURGE 090. Introduce the team and milestone scope.

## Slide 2

ACTUATOR SELECTION STUDY

Why Dynamixel Motors?

OPTIONS COMPARED

Criterion | Conventional Servo | Dynamixel Smart Servo
Communication | Individual signal wire per motor | Daisy-chain communication
Wiring Complexity | High | Low
Feedback | Not available | Position, load, temperature, voltage feedback
Controller | External controller required | Built-in controller
Scalability | Difficult for many joints | Designed for multi-joint robots
Precision | Moderate | High
Robotics Applications | Hobby projects | Research and industrial robotics

THE REQUIREMENT

A snake robot drives many joints at once. The actuator must deliver:

- Precise position control
- Simple wiring architecture
- Scalability for multiple joints
- Reliable communication
- Real-time feedback
- Compact size & sufficient torque

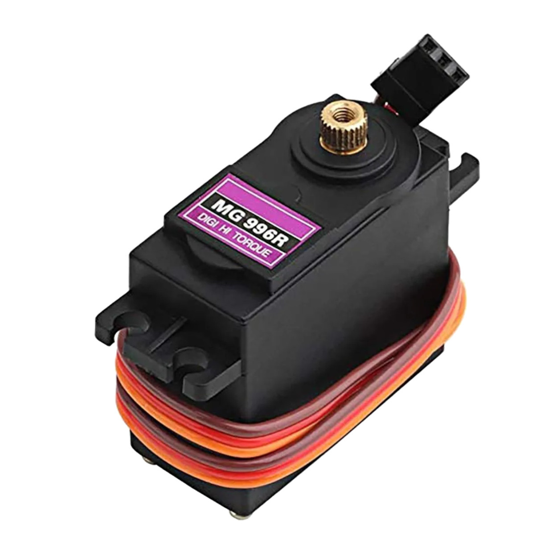
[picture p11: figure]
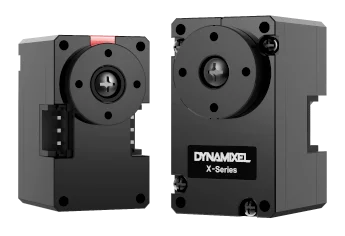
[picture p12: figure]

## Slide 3

ARCHITECTURE & DECISION

Daisy-Chain Architecture & Final Selection

Conventional Servo — Separate Wiring

Every motor needs its own signal wire back to the controller.

Dynamixel — Daisy-Chain

One cable carries power and data to every joint in sequence.

Controller

Servo 1

Servo 2

Servo 3

Ctrl

M1

M2

M3

M4

Servo 4

KEY LEARNINGS

- Daisy-chain wiring sharply cuts cabling and assembly effort.
- A controller built into every motor simplifies integration.
- Real-time feedback enables future closed-loop control.
- Compact form factor suits modular robot segments.
- High precision and smart control fit advanced robotics.

FINAL SELECTED ACTUATOR

Dynamixel XL330 Series

Chosen for its smart serial communication, full-state feedback, compact form factor and effortless multi-joint scaling — the right fit for a multi-segment snake robot.

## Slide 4

GOALS & EXPECTED OUTCOMES

What This Project Sets Out to Build

Modular Architecture

A repeatable segment-based mechanical design.

Dynamixel Actuators

Integrate smart servos with daisy-chained control.

Raspberry Pi Control

A single-board-computer control system.

01

02

03

Locomotion Algorithms

Implement serpentine and gait-based motion.

Sensor Integration

Add sensing for future intelligent navigation.

Scalable Platform

Keep it maintainable and easy to extend.

04

05

06

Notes: Six concrete goals across mechanics, actuation, computing, control, sensing and scalability. These map to the timeline phases.

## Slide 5

WORK COMPLETED SO FAR

Quarter-One Progress Summary

COMPLETED TASKS

OVERALL COMPLETION(till now)

25 %

Phase 1 complete · Phase 2 underway

Literature review & project understanding

Raspberry Pi setup & configuration

Hardware selection & BOM preparation

Wi-Fi connectivity testing on the Pi

CAD design of snake-robot segment

Basic Raspberry Pi lab projects executed

10

Tasks done

2

Segments printed

1

Pi configured

Assembly sized to Dynamixel XL330 dims

GitHub repository created & maintained

3D printing of two prototype segments

Procurement process initiated

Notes: About a quarter done: ten tasks closed across research, mechanical design, fabrication and the compute platform.

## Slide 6

SYSTEM ARCHITECTURE

Conceptual Block Diagram

Architecture finalized · Implementation in progress

FUTURE INTEGRATION

IMU / Force Sensors

Power Supply

Raspberry Pi 5 [Central Controller]

Control Algorithms

Camera Module

Communication Layer (U2D2 / UART)

Wireless Control Module

Dynamixel Motor Network

Robot Segments (10 × servo joints)

LEGEND

Implemented

In Progress

Current Implementation Status

Planned Future Work

Raspberry Pi 5 configured and tested

Communication architecture defined

Mechanical segments fabricated

Dynamixel integration pending hardware

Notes: Controller at the centre. Solid cyan = implemented/in progress; dashed amber (sensors, camera) = designed-in but scheduled for a later phase.

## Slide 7

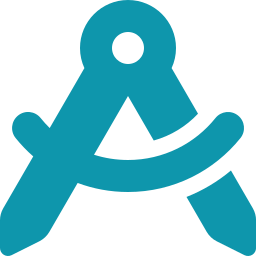
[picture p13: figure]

ASSEMBLY FLOW

Motor → Segment Parts → Full Chain Assembly

③ Full Assembly

CAD DESIGN DEVELOPMENT

A Segment Designed Around the Motor

The CAD model is built to the exact dimensions of the Dynamixel XL330-M288 servo, using a modular, segment-based architecture focused on manufacturability and scalability.

DESIGN CONSIDERATIONS

Motor mounting — Precise seats for XL330 servo bodies.

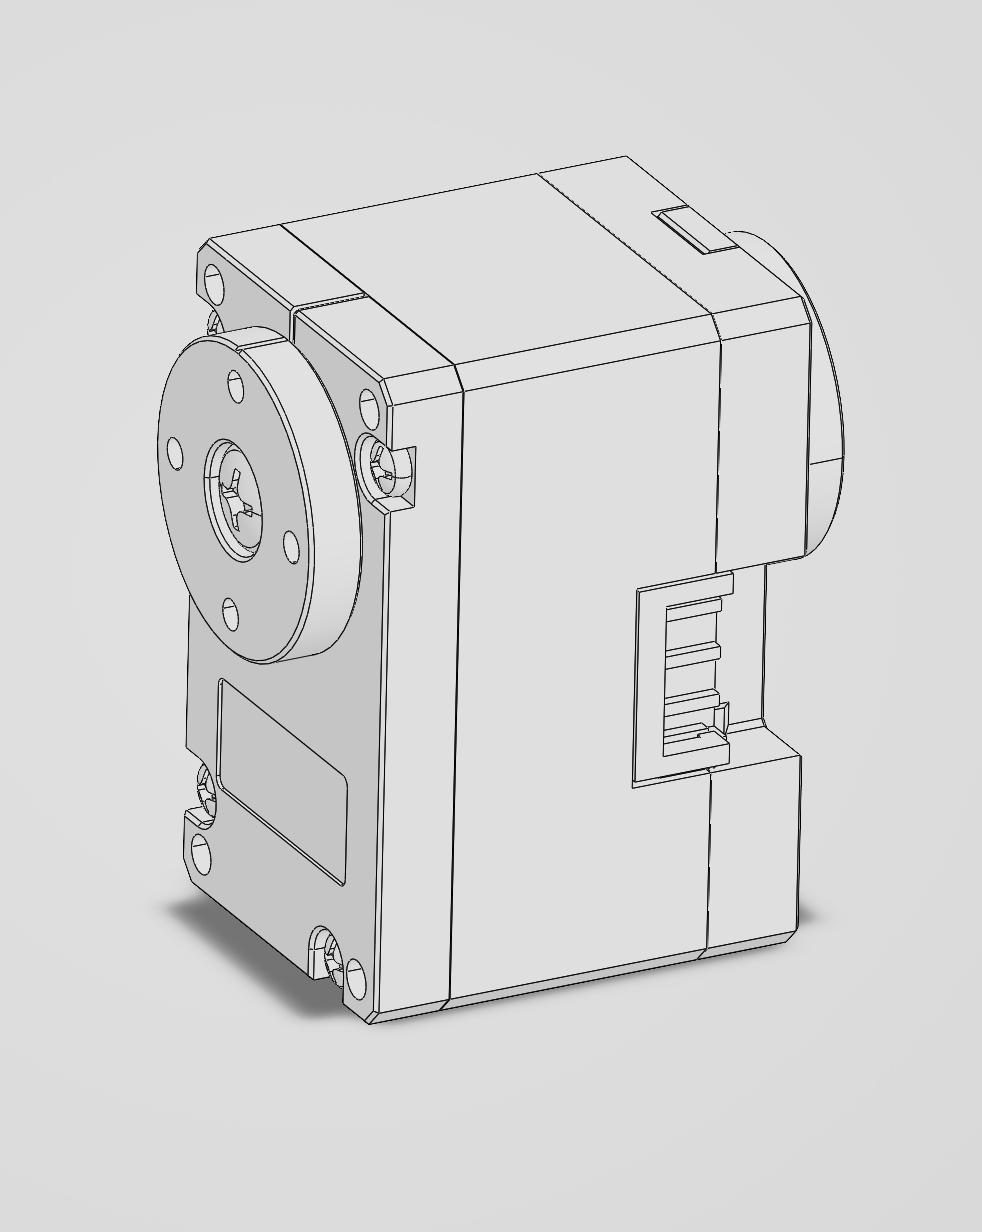
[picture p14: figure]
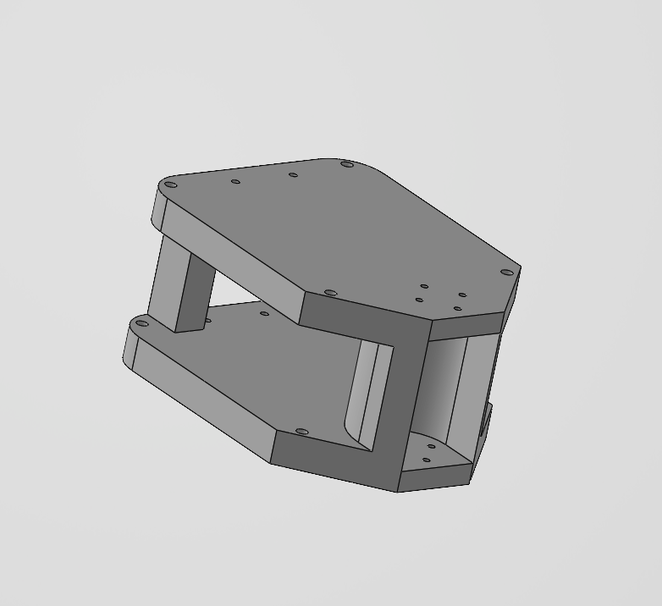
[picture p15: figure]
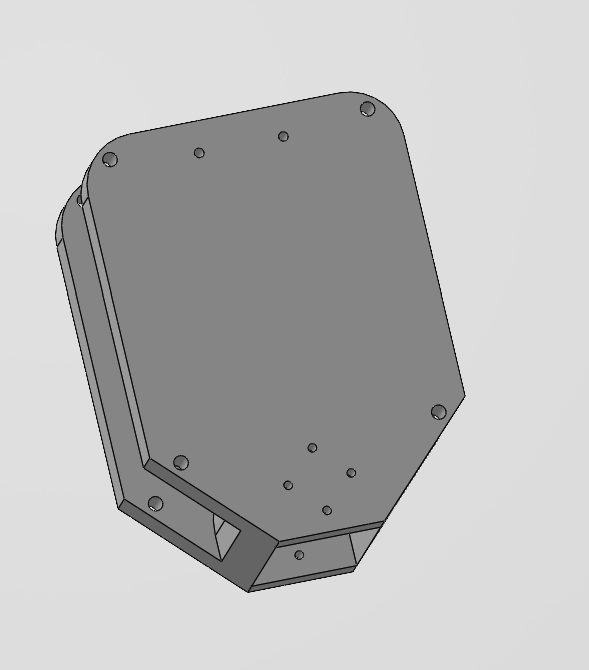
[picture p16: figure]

Structural rigidity — Stiff frame to resist motion loads.

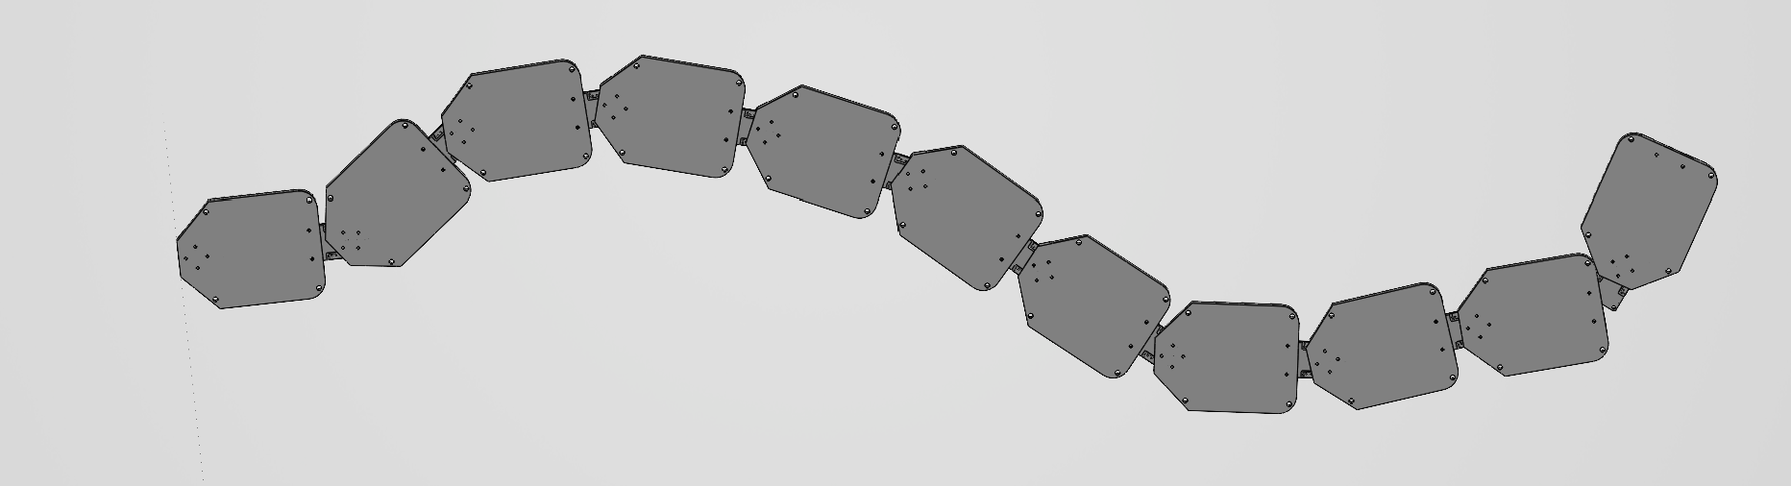
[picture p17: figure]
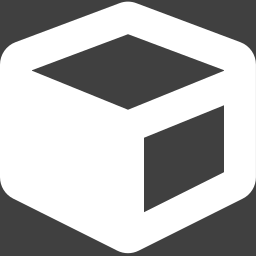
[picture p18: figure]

Cable routing — Clean daisy-chain channels for wiring.

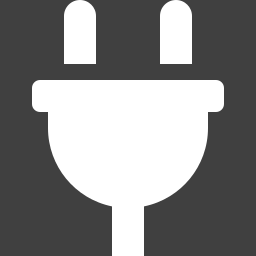
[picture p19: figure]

Electronics ready — Space reserved for future boards.

① Motor

② Segment Parts

③ Full Assembly

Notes: CAD modelled to real XL330 dimensions so printed parts mate with the actual servos. Replace the placeholder with CAD screenshots.

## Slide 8

PROTOTYPE FABRICATION

From Model to Printed Hardware

PRINTED SEGMENT — PHOTO 1

Insert photo of the first 3D-printed segment

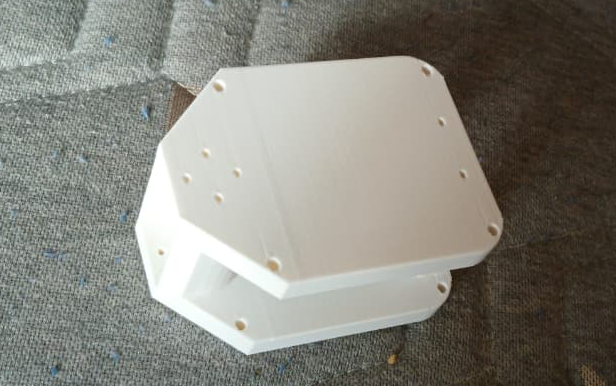
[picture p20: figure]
The image shows a white, rectangular piece of furniture, possibly a desk or shelf, resting on a patterned carpet with a few scattered fabric scraps nearby.

FABRICATION STATUS

Two prototype segments 3D printed

Both segments produced from the CAD model.

DONE

Initial dimensional verification done

Printed parts measured against design specs.

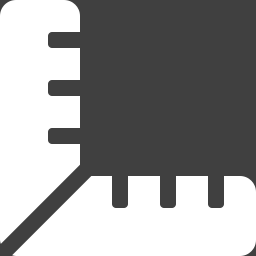
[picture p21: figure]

DONE

PRINTED SEGMENT — PHOTO 2

Insert photo of the second segment / assembly

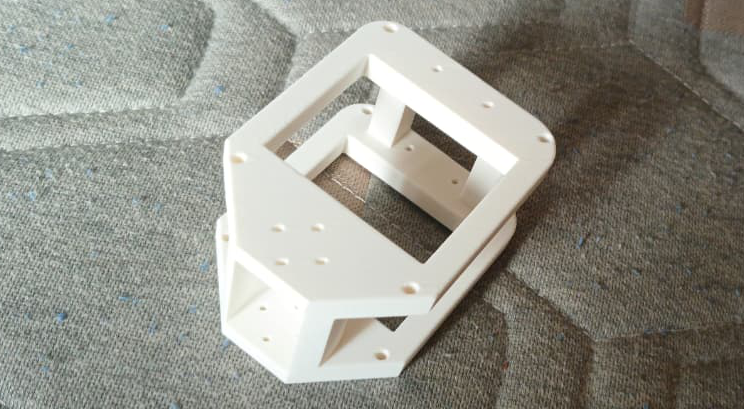
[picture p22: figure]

Physical validation of CAD initiated

Checking fit, tolerances and assembly.

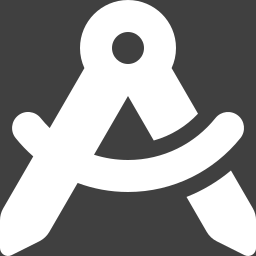
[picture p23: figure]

NEXT

Preparing for motor-integration tests

Next: seat XL330 servos into segments.

NEXT

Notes: Two segments printed and measured, validating the CAD. Next step is servo integration. Drop prototype photos on the left.

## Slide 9

RASPBERRY PI LEARNING & DEVELOPMENT

Standing Up the Compute Platform

PROGRESS MILESTONES

Raspberry Pi 5 received & configured

Raspberry Pi OS installation completed

Wi-Fi connectivity established

SSH & remote access explored

Basic GPIO & intro projects performed

Linux environment & Python familiarity

Development Environment Setup

Raspberry Pi OS Desktop

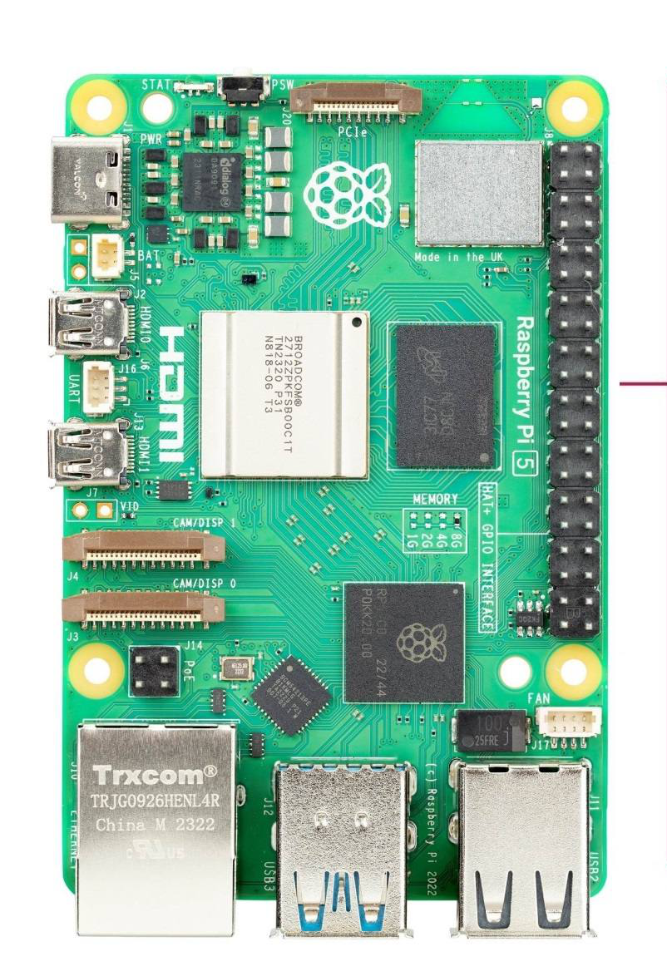
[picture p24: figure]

GPIO / Python Testing

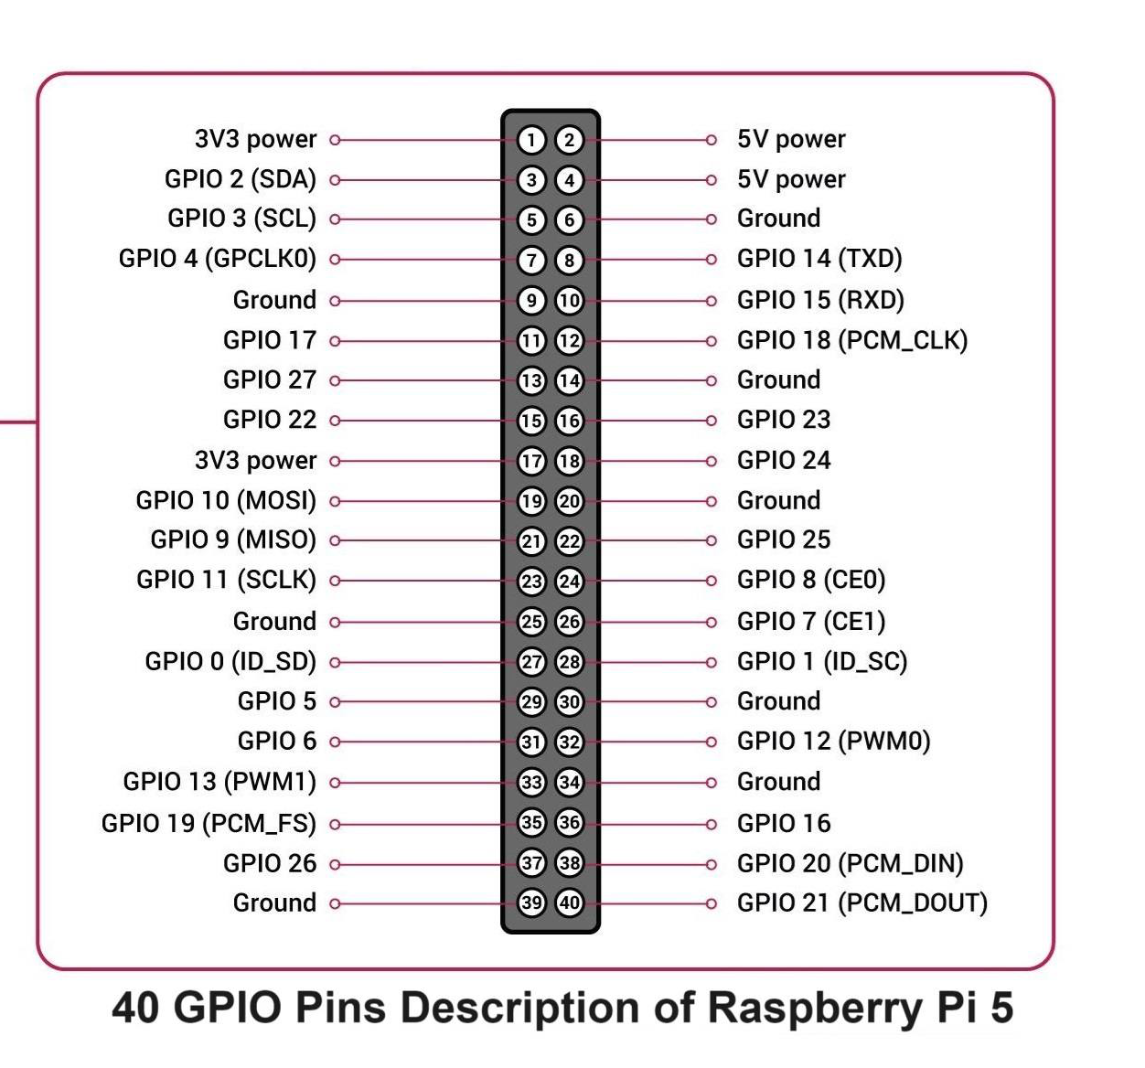
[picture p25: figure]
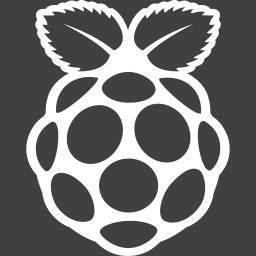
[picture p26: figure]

SSH Remote Access

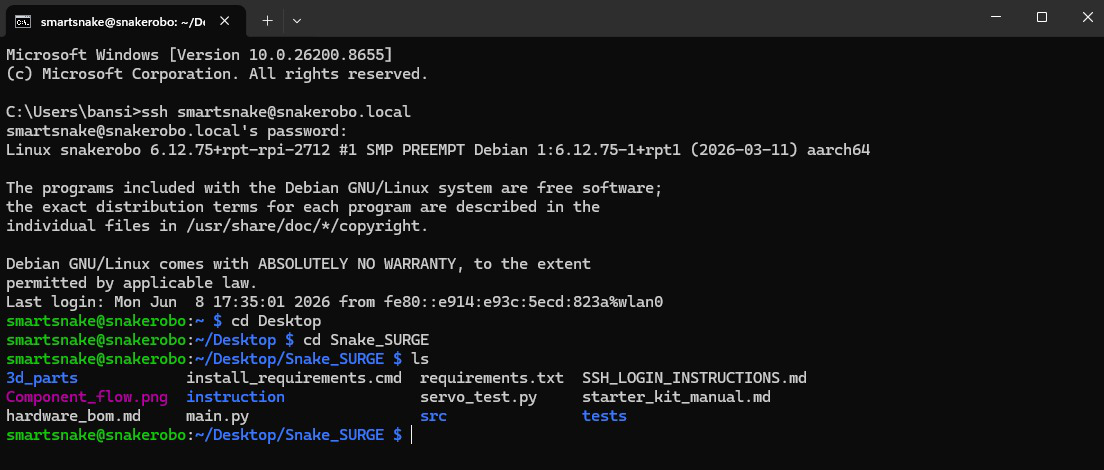
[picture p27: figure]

System Configuration

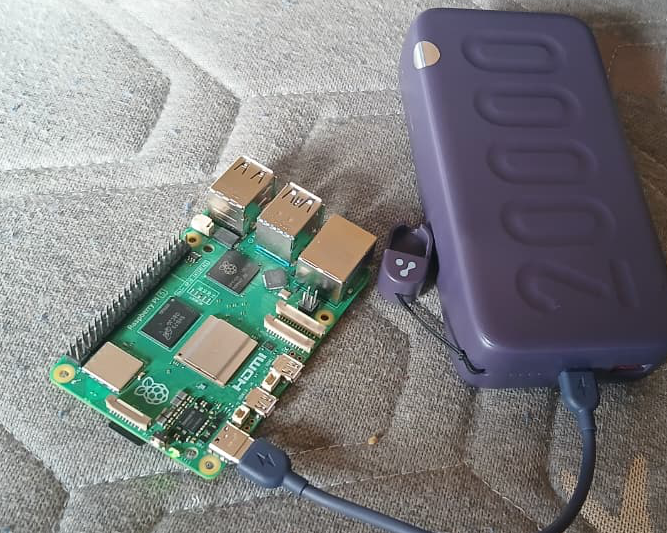
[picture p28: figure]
The image shows a purple rectangular device, presumably a Raspberry Pi E, with four black USB ports, placed on a wooden surface.

Raspberry Pi Platform Successfully Configured and Tested

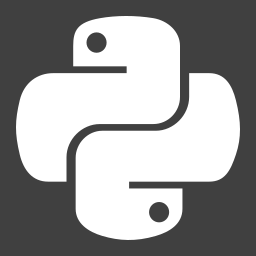
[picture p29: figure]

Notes: Control computer is live: OS installed, networked, remotely accessible, exercised with intro GPIO and Python. De-risks software before motors arrive.

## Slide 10

HARDWARE PROCUREMENT & RESOURCE AVAILABILITY

Hardware Procurement & Resource Availability

Hardware Strategy: Raspberry Pi 4 was planned in the BOM; however, a Raspberry Pi 5 was already available in the laboratory, enabling immediate software development and testing without waiting for delivery. To accelerate development, the team utilised the laboratory Raspberry Pi 5 platform while the ordered components remain under procurement.

DEVELOPMENT PROGRESS

Key Achievement: Although the primary Dynamixel hardware has not yet arrived, the team has successfully utilised available laboratory resources to complete design, fabrication, documentation, and software preparation activities, ensuring project progress is maintained.

AVAILABLE & IN USE

- Raspberry Pi 5 (Laboratory Resource)
- Raspberry Pi Starter Kit
- Raspberry Pi OS Environment
- GitHub Repository
- 3D Printed Prototype Segments

ORDERED — AWAITING DELIVERY

- Dynamixel XL330 Smart Servo Motors
- U2D2 Communication Interface
- U2D2 Power Hub Board
- Dynamixel Communication Cables
- 5V Power Supply
- ESP32 Development Board

COMPLETED PREPARATORY WORK

- Hardware selection finalised
- Bill of Materials prepared
- CAD model completed
- Segment fabrication initiated
- Software environment configured

✓

✓

✓

✓

✓

⏳

→

Component
Selection

Procurement
Initiated

CAD
Design

Prototype
Printing

RPi
Learning

Motor
Integration

Awaiting HW

Locomotion
Testing

Upcoming

★

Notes: Live BOM from the purchasing sheet. Compute hardware in hand; actuation and power chain ordered. Total approx Rs 33,760.

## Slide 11

REPOSITORY & DOCUMENTATION

Version Control From Day One

GitHub repository — project root & structure

Repository created
Central home for the whole project.

1

GITHUB REPOSITORY SCREENSHOTS

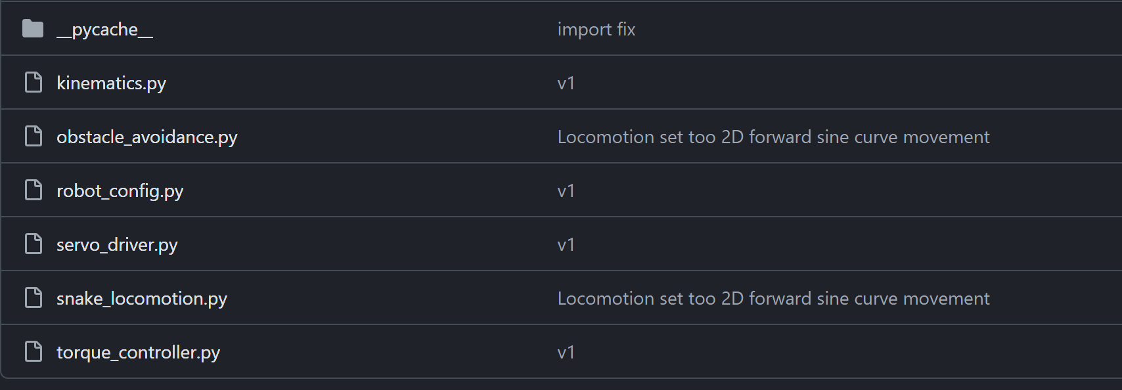
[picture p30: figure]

2

Version control established
Tracked, reversible change history.

CAD files uploaded
Design source committed to the repo.

3

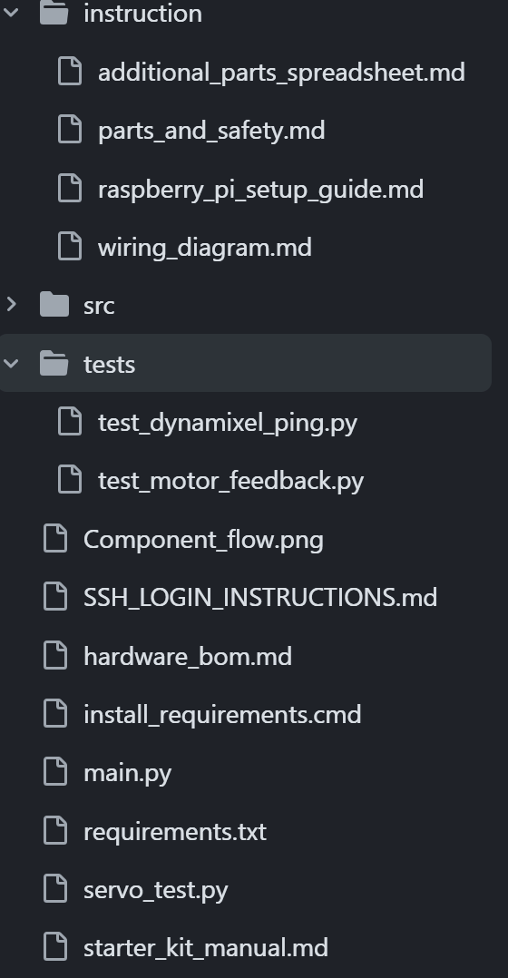
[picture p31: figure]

4

Design iterations documented
Every revision captured in commits.

Commit history — tracked iterations & uploads

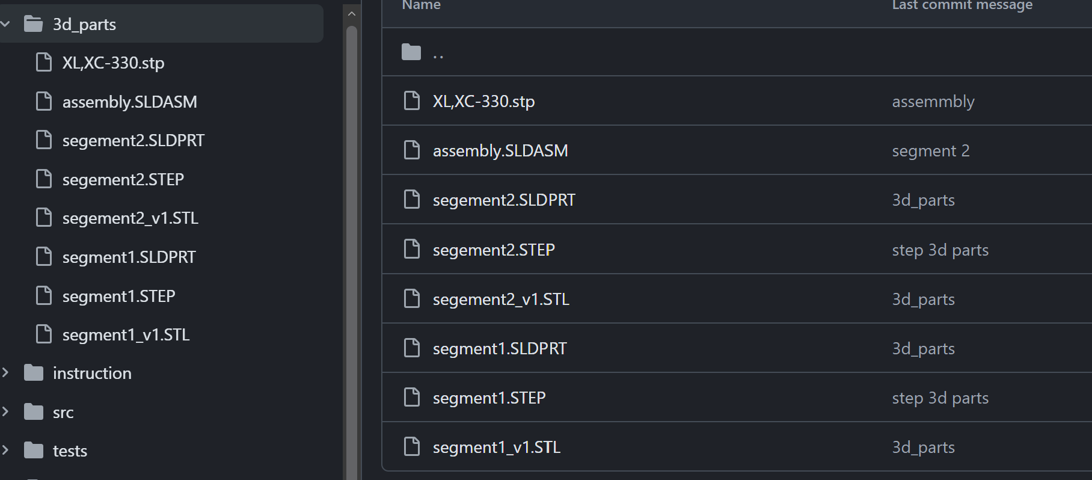
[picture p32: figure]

Progress tracking in place
Milestones and issues logged.

5

Team collaboration workflow
Shared branches and pull requests.

✓ All milestones tracked in GitHub

6

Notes: The repo is the single source of truth — CAD, docs, tracked iterations — with a collaboration workflow already running.

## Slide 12

PROJECT TIMELINE

Eight Phases · Currently at 25%

PHASE 1

Research & Design

Completed

PHASE 3

Mechanical Assembly

Up next

PHASE 5

Control Algorithms

PHASE 7

Testing & Optimisation

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
PHASE 2

Hardware Procurement

In progress

PHASE 4

Motor Integration

PHASE 6

Sensor Integration

PHASE 8

Final Demonstration

WE ARE HERE

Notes: Eight-phase plan: Phase 1 complete, Phase 2 active, Phase 3 next — about 25%. Phases 4-8 cover integration, control, sensing, testing, demo.

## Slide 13

CURRENT ACHIEVEMENTS

Concrete Wins in Quarter One

Architecture finalized

System block diagram locked.

CAD design completed

Segment modelled to motor specs.

Prototype fabrication started

Two segments printed & checked.

Pi environment established

OS, network and tooling ready.

GitHub workflow operational

Version control and docs live.

Procurement initiated

Core compute received; rest ordered.

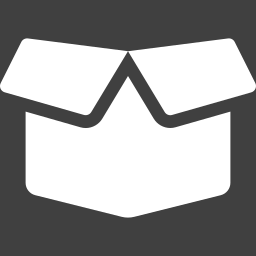
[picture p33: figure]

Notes: Six headline achievements: design, fabrication, compute, tooling and procurement all moving — a working foundation.

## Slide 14

SIMULATION & VALIDATION

Simulation-Based Validation of Control Architecture

Wokwi-based simulation environment developed to validate locomotion control, sensor integration, and communication architecture before physical Dynamixel hardware arrival.

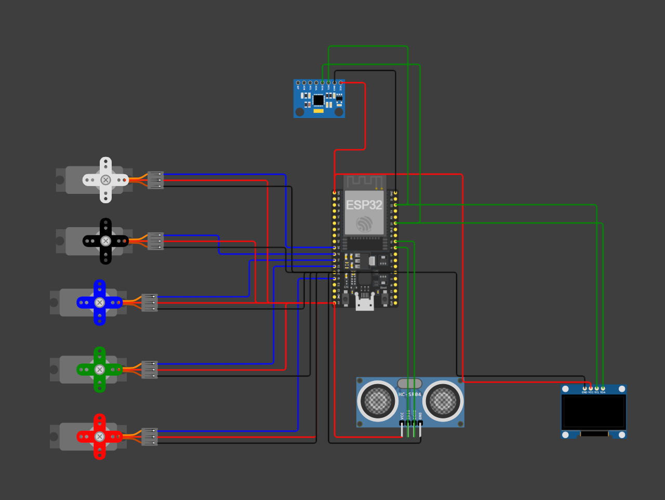
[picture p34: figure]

SIMULATION OBJECTIVE

A virtual testing platform to validate the control architecture before Dynamixel actuators and communication hardware arrive — enabling software development, algorithm verification, and sensor integration in parallel with procurement.

COMPONENTS SIMULATED

Controller

ESP32 · 5-Servo joint network · MPU6050 IMU · HC-SR04 ultrasonic · SSD1306 OLED · control & communication framework

FUNCTIONAL VALIDATION COMPLETED

- Multi-joint servo coordination
- Travelling-wave serpentine gait generation
- Obstacle detection via ultrasonic sensing
- IMU integration for orientation feedback
- OLED-based system status monitoring
- Sensor–controller–actuator communication

Sensors

Display

Actuators

ENGINEERING BENEFITS

- Reduced dependence on hardware delivery timelines
- Enabled early software debugging & control-architecture verification
- Established migration path to Raspberry Pi 5 + Dynamixel XL330, reducing integration risk

KEY OUTCOME A complete software-validation framework was developed, allowing locomotion, sensing, and control workflows to be tested before physical robot assembly.

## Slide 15

FUTURE WORK & DEVELOPMENT ROADMAP

Planned Activities for the Next Development Phase

Hardware Arrival

1

Mechanical Assembly

2

Communication Setup

3

Locomotion Development

4

Sensor Integration

5

Testing & Optimization

6

- Receive Dynamixel XL330 motors
- Receive U2D2 interface
- Verify purchased components

Completed phase

- Assemble complete snake body
- Install Dynamixel actuators
- Route communication cables

Ongoing work

- Configure motor IDs
- Establish serial communication
- Validate daisy-chain architecture

Future milestone

- Port simulation code to Pi 5
- Implement serpentine locomotion
- Synchronize multi-joint movement

- Integrate MPU6050 IMU
- Integrate obstacle detection
- Implement feedback control

- Motion performance testing
- Power & reliability analysis
- System optimization

EXPECTED DELIVERABLES

- Fully assembled snake robot
- Dynamixel-based locomotion
- Sensor-assisted navigation
- Integrated Raspberry Pi 5 control system
- Demonstration-ready prototype
- Final SURGE project showcase

TARGET FOR NEXT REVIEW

- Complete hardware integration
- Demonstrate basic snake locomotion
- Validate communication architecture
- Validate sensing framework

Goal: ~60–70% project completion

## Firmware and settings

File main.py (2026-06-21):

#!/usr/bin/env python
# -*- coding: utf-8 -*-

"""
Main control loop for SURGE-SNAKE.
Integrates locomotion kinematics, Dynamixel SDK hardware calls, and obstacle avoidance.
"""

import sys
import time

from dynamixel_sdk import PortHandler, PacketHandler, COMM_SUCCESS

from src.robot_config import Config, DynamixelAddr
from src.snake_locomotion import SnakeKinematics
from src.obstacle_avoidance import ObstacleAvoidance
from src.utils import to_signed_current

# --- Hardware Configuration ---
# Automatically select the correct serial port for each OS.
if sys.platform.startswith('win'):
    DEVICENAME = 'COM3'
else:
    DEVICENAME = '/dev/ttyUSB0'   # Default port on Raspberry Pi


# ---------------------------------------------------------------------------
# Motor initialisation / shutdown helpers
# ---------------------------------------------------------------------------

def init_motors(packet_handler, port_handler, num_motors: int) -> None:
    """Enable torque on every motor in the daisy chain."""
    for dxl_id in range(1, num_motors + 1):
        result, error = packet_handler.write1ByteTxRx(
            port_handler, dxl_id, DynamixelAddr.TORQUE_ENABLE, 1
        )
        if result != COMM_SUCCESS:
            print(
                f"[ERROR] Failed to enable torque for Motor {dxl_id}: "
                f"{packet_handler.getTxRxResult(result)}"
            )
        elif error != 0:
            print(f"[WARN ] Motor {dxl_id} torque enable returned hardware error: "
                  f"{packet_handler.getRxPacketError(error)}")
        else:
            print(f"[OK   ] Torque enabled for Motor {dxl_id}")


def disable_motors(packet_handler, port_handler, num_motors: int) -> None:
    """Disable torque on every motor so the snake can be moved freely."""
    for dxl_id in range(1, num_motors + 1):
        packet_handler.write1ByteTxRx(
            port_handler, dxl_id, DynamixelAddr.TORQUE_ENABLE, 0
        )


# ---------------------------------------------------------------------------
# Main control loop
# ---------------------------------------------------------------------------

def main() -> None:
    print("--- SURGE-SNAKE Initializing ---")

    num_motors = Config.NUM_JOINTS   # 10

    # --- Open serial port ---
    port_handler   = PortHandler(DEVICENAME)
    packet_handler = PacketHandler(Config.PROTOCOL_VERSION)

    if not port_handler.openPort():
        print(f"[FATAL] Failed to open port '{DEVICENAME}'. "
              "Check USB connection and COM port setting.")
        return

    if not port_handler.setBaudRate(Config.BAUDRATE):
        port_handler.closePort()   # Clean up the already-opened port
        print(f"[FATAL] Failed to set baud rate to {Config.BAUDRATE}.")
        return

    # --- Initialise motors ---
    init_motors(packet_handler, port_handler, num_motors)

    # --- Initialise logic modules ---
    kinematics = SnakeKinematics(num_motors=num_motors)
    avoidance  = ObstacleAvoidance()   # thresholds/timings come from Config defaults

    start_time = time.time()
    print("\nStarting Main Control Loop. Press Ctrl+C to stop.")

    try:
        while True:
            current_time = time.time() - start_time

            # 1. Read Feedback (Sensors) ----------------------------------------
            motor_currents: dict[int, int] = {}
            for dxl_id in range(1, num_motors + 1):
                raw_current, result, _ = packet_handler.read2ByteTxRx(
                    port_handler, dxl_id, DynamixelAddr.PRESENT_CURRENT
                )
                if result == COMM_SUCCESS:
                    motor_currents[dxl_id] = to_signed_current(raw_current)
                else:
                    # Log read failure but keep going; missing one reading is recoverable
                    print(f"[WARN ] Current read failed for Motor {dxl_id}: "
                          f"{packet_handler.getTxRxResult(result)}")
                    motor_currents[dxl_id] = 0

            # 2. State Machine Evaluation (Obstacle Detection & Evasion) --------
            current_state = avoidance.process_state(current_time, motor_currents)

            # 3. Kinematics — calculate target encoder positions -----------------
            target_positions = kinematics.calculate_positions(
                current_time,
                mode=current_state,
                turn_direction=avoidance.turn_direction,
            )

            # 4. Actuation — send goal positions to each motor ------------------
            for dxl_id, pos in target_positions.items():
                result, error = packet_handler.write4ByteTxRx(
                    port_handler, dxl_id, DynamixelAddr.GOAL_POSITION, pos
                )
                if result != COMM_SUCCESS:
                    print(f"[ERROR] Position write failed for Motor {dxl_id}: "
                          f"{packet_handler.getTxRxResult(result)}")
                elif error != 0:
                    print(f"[WARN ] Motor {dxl_id} hardware error on write: "
                          f"{packet_handler.getRxPacketError(error)}")

            # Small delay to avoid saturating the serial bus (~50 Hz loop)
            time.sleep(Config.DT)

    except KeyboardInterrupt:
        print("\nHalting Snake...")
    finally:
        disable_motors(packet_handler, port_handler, num_motors)
        port_handler.closePort()
        print("Shutdown complete.")


if __name__ == '__main__':
    main()

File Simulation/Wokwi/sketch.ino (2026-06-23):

/*
  SURGE090 — Serpentine Snake Robot Controller
  ESP32 + 5x Servo + MPU6050 + HC-SR04 + SSD1306 OLED
  ------------------------------------------------------------------
  Improvements over the original:
    - All tuning lives in one CONFIG block (amplitude, speed, wave,
      turn, center, per-servo trim & direction).
    - Real serpenoid gait with selectable modes: FWD / REV / LEFT /
      RIGHT / IDLE / AUTO (autonomous obstacle avoidance).
    - Non-blocking loop (millis() scheduling) — servos, sensor and
      display each run on their own timers. No more delay(30).
    - Robust ultrasonic: pulseIn timeout + exponential smoothing,
      plus hysteresis so the robot doesn't twitch at the threshold.
    - MPU6050 flip/fall detection — stops moving if it tips over.
    - Live tuning over the Serial Monitor (115200 baud) — type ?
    - Graceful startup: a missing OLED/MPU no longer bricks the bot.
  ------------------------------------------------------------------
  Gait model (lateral undulation / serpenoid curve):
    angle_i = center + trim_i + bias + dir_i * A * sin(phase + d*i*lag)
*/

#include <Adafruit_GFX.h>
#include <Adafruit_MPU6050.h>
#include <Adafruit_SSD1306.h>
#include <Adafruit_Sensor.h>
#include <ESP32Servo.h>
#include <Wire.h>

// ============================================================
//  USER CONFIGURATION  — tweak everything here
// ============================================================

// ---- Display ----
#define SCREEN_WIDTH 128
#define SCREEN_HEIGHT 64
#define OLED_ADDR 0x3C

// ---- Ultrasonic ----
#define TRIG_PIN 5
#define ECHO_PIN 18
#define MAX_DISTANCE_CM 400.0f // readings above this are clamped
#define OBSTACLE_CM 20.0f      // stop / avoid below this
#define CLEAR_CM 25.0f         // resume above this (hysteresis gap)

// ---- I2C (shared by OLED + MPU6050) ----
#define I2C_SDA 21
#define I2C_SCL 22

// ---- Servos ----
#define NUM_SERVOS 5
const int SERVO_PINS[NUM_SERVOS] = {26, 27, 14, 12, 13};

// Per-servo trim (deg) so each truly centers. Adjust if a joint sags.
int servoTrim[NUM_SERVOS] = {0, 0, 0, 0, 0};

// Flip a servo if it's mounted mirrored: use +1 or -1.
int servoDir[NUM_SERVOS] = {1, 1, 1, 1, 1};

// ---- Gait defaults (all live-adjustable over Serial) ----
struct GaitConfig {
  float amplitude; // degrees of swing from center
  float waveLag;   // phase offset between adjacent segments (rad)
  float speed;     // phase step per update -> wave frequency
  float turnBias;  // degrees added to every joint to steer
  int centerAngle; // neutral position
};
GaitConfig gait = {40.0f, 0.8f, 0.12f, 0.0f, 90};

// ---- Timing (non-blocking, ms) ----
const unsigned long SERVO_INTERVAL = 20;    // ~50 Hz gait update
const unsigned long SENSOR_INTERVAL = 60;   // ultrasonic + IMU poll
const unsigned long DISPLAY_INTERVAL = 120; // OLED refresh

// ---- Safety ----
#define ENABLE_FLIP_STOP true
#define FLIP_ACCEL_Z -4.0f // Az below this => robot is upside down

// ============================================================
//  STATE
// ============================================================
enum Mode {
  MODE_FORWARD,
  MODE_BACKWARD,
  MODE_LEFT,
  MODE_RIGHT,
  MODE_IDLE,
  MODE_AUTO
};
Mode currentMode = MODE_AUTO;

Servo servos[NUM_SERVOS];
Adafruit_SSD1306 display(SCREEN_WIDTH, SCREEN_HEIGHT, &Wire, -1);
Adafruit_MPU6050 mpu;
bool mpuOk = false;
bool displayOk = false;

float phase = 0.0f;
float distSmooth = MAX_DISTANCE_CM;
bool moving = true;
bool flipped = false;

sensors_event_t accel, gyro, mtemp;
unsigned long tServo = 0, tSensor = 0, tDisplay = 0;

// Forward declarations (safe whether compiled as .ino or .cpp)
void printStatus();
const char *modeName(Mode m);

// ============================================================
//  ULTRASONIC
// ============================================================
float readDistanceRaw() {
  digitalWrite(TRIG_PIN, LOW);
  delayMicroseconds(2);
  digitalWrite(TRIG_PIN, HIGH);
  delayMicroseconds(10);
  digitalWrite(TRIG_PIN, LOW);

  unsigned long dur = pulseIn(ECHO_PIN, HIGH, 25000UL); // ~4 m timeout
  if (dur == 0)
    return MAX_DISTANCE_CM; // no echo = clear
  float d = dur * 0.0343f / 2.0f;
  return (d > MAX_DISTANCE_CM) ? MAX_DISTANCE_CM : d;
}

void filterDistance(float raw) {
  const float alpha = 0.4f; // 0..1, higher = snappier, lower = smoother
  distSmooth = alpha * raw + (1.0f - alpha) * distSmooth;
}

// ============================================================
//  GAIT
// ============================================================
void applyGait(float waveDir, float bias) {
  for (int i = 0; i < NUM_SERVOS; i++) {
    float a =
        gait.centerAngle + servoTrim[i] + bias +
        servoDir[i] * gait.amplitude * sin(phase + waveDir * i * gait.waveLag);
    a = constrain(a, 0.0f, 180.0f);
    servos[i].write((int)a);
  }
  phase += gait.speed;
  if (phase >= TWO_PI)
    phase -= TWO_PI;
}

void holdNeutral() {
  for (int i = 0; i < NUM_SERVOS; i++)
    servos[i].write(constrain(gait.centerAngle + servoTrim[i], 0, 180));
}

void updateGait() {
  switch (currentMode) {
  case MODE_FORWARD:
    applyGait(+1, gait.turnBias);
    break;
  case MODE_BACKWARD:
    applyGait(-1, gait.turnBias);
    break;
  case MODE_LEFT:
    applyGait(+1, gait.turnBias + 25);
    break;
  case MODE_RIGHT:
    applyGait(+1, gait.turnBias - 25);
    break;
  case MODE_IDLE:
    holdNeutral();
    break;
  case MODE_AUTO:
    if (flipped)
      holdNeutral(); // tipped over
    else if (moving)
      applyGait(+1, gait.turnBias); // clear path
    else
      applyGait(+1, gait.turnBias + 30); // veer around obstacle
    break;
  }
}

// ============================================================
//  IMU SAFETY
// ============================================================
void checkFlip() {
  if (!ENABLE_FLIP_STOP || !mpuOk) {
    flipped = false;
    return;
  }
  flipped = (accel.acceleration.z < FLIP_ACCEL_Z); // upright Az ~ +9.8
}

// ============================================================
//  SERIAL COMMAND INTERFACE
// ============================================================
const char *modeName(Mode m) {
  switch (m) {
  case MODE_FORWARD:
    return "FWD";
  case MODE_BACKWARD:
    return "REV";
  case MODE_LEFT:
    return "LEFT";
  case MODE_RIGHT:
    return "RIGHT";
  case MODE_IDLE:
    return "IDLE";
  case MODE_AUTO:
    return "AUTO";
  }
  return "?";
}
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

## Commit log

2026-06-21 Reorganized repository structure and documentation
    [XL,XC-330.SLDASM, XL,XC-330.stp, assembly.SLDASM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]
2026-06-23 Restructure repository layout and add ESP32 software validation simulation
    - Reorganized project workspace into standard, clean directories:
    - CAD/ : Mechanical design models (Segment STL and Assembly STEP)
    - Documentation/: Progress reports and review presentations
    - Simulation/ : Software validation configurations and firmware
    - Images/ : CAD renders, physical prints, and architectural diagrams
    - Hardware/ : Procurement selection guides and spreadsheet budgets
    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
    [Assembly.step, BOM.xlsx, Segment_v1.stl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]
2026-06-23 after simulation
    [XL,XC-330.SLDASM, XL,XC-330.stp, assembly.SLDASM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]
